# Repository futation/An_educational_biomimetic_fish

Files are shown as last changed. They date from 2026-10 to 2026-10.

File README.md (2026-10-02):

# 一种教育型仿生鱼

一种教育型仿生鱼，用于学生或者极客上手体验。

基于 Arduino Nano 的蓝牙遥控仿生机器鱼：3D 打印外壳 + 自焊 PCB + 防水舵机鱼尾，全套设计开源，适合作为中小学生与电子 DIY 爱好者的手工/电子入门项目。

English documentation: see [`使用说明（英文版）/`](使用说明（英文版）/Getting%20Started.md)

## 功能特点

- 蓝牙遥控：BLE / SPP 双模串口透传，手机发指令即可控制
- 多档摆动控制：±15° / ±30° / ±45° 摆幅，低速 / 高速两档，支持鱼尾回中与持续左右摆动
- 中位角度可通过指令调节，掉电保存于 EEPROM
- 全套开源：源码、PCB 工程、3D 打印外壳、组装与使用教程

## 仓库结构

| 目录 | 内容 |
| --- | --- |
| `Code/` | Arduino Nano 源码（`fish.ino` 与舵机/模式/EEPROM 模块） |
| `PCB/` | 立创EDA专业版 PCB 工程（`PCB.epro2`） |
| `外壳文件/` | 3D 打印外壳 STEP 文件（对接版本 / 旋钮版本两种方案） |
| `使用说明/` | 上手教程与控制指令说明（中文，md + pdf） |
| `使用说明（英文版）/` | English documentation (md + pdf) |
| `组装说明/` | 从 0 到 1 组装教程：备料、焊接、烧录、下水防水 |
| `软件/` | 配套手机端蓝牙调试软件（第三方转载，见其 README） |
| `image/` | 各说明文档所引用的图片与演示视频 |

## 快速上手

1. **组装**：3D 打印外壳，按 [组装说明](组装说明/仿生鱼V1.md) 完成备料、PCB 焊接、舵机安装与配重
2. **烧录**：安装 Arduino IDE，打开 `Code/fish/fish.ino`，开发板选 Arduino Nano，按文档处理烧录时的蓝牙占用问题
3. **连接**：手机安装 [`软件/蓝牙调试器_v1.95.apk`](软件/蓝牙调试器_v1.95.apk)（第三方软件，版权归原作者所有），磁铁开启小鱼电源后蓝牙连接
4. **控制**：发送 `CMD_a` / `CMD_A` 等指令让鱼游起来，详见 [使用说明](使用说明/鱼上手说明.md) 与 [控制命令说明](使用说明/鱼控制命令说明.md)

## 开发环境

- 主控：Arduino Nano（ATmega328P），Arduino IDE + Servo 库
- 蓝牙：DX-BT04 双模透传模块（建议选带 BLE 协议的型号）
- EDA：立创EDA专业版（直接打开 `PCB/PCB.epro2`）
- 外壳：通用 FDM 3D 打印机，STEP 格式可直接导入切片/建模软件

## 许可证

本项目以 [MIT](LICENSE) 协议开源。

其中 `软件/蓝牙调试器_v1.95.apk` 为第三方软件的转载，仅供下载便利，版权归其原作者所有；也可以改用任意其他 BLE 调试工具。

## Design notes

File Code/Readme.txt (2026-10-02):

For simplicity, 
SmartFish developed using Arduino IDE and Arduino Nano as the main controller. 
The source code is provided in this folder for learning purposes

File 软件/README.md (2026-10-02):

# 软件

本目录存放仿生鱼的配套手机端控制软件安装包。

| 文件 | 说明 |
| --- | --- |
| `蓝牙调试器_v1.95.apk` | Android 蓝牙调试软件，用于给小鱼发送控制指令（安装包原名 `lanyatiaoshiqi_v1.95_3673.com.apk`） |

## 来源说明

**该软件来自第三方网络，本项目仅转载安装包以便读者下载使用，软件版权归原开发者所有。**

- 软件名称：蓝牙调试器（BT Controller）
- 版本：v1.95
- 开发者：XieLazyDog（Xie Rongji）
- 开发者主页：<https://github.com/xielazydog>
- 应用仓库：<https://github.com/xielazydog/BTController>

如开发者不希望该软件被转载，请联系删除。你也可以在应用商店自行搜索"蓝牙调试器"获取最新版本。

> 其他任意支持 BLE 的蓝牙调试软件（如 BLE 调试助手）同样可用于控制小鱼。

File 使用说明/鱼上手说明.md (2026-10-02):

本项目小鱼是一款 兴趣教学 类 产品 ，为中小学生 ，电子 DIY 爱好者 提供 愉快的 手工项目体验。

以下为小鱼的直接上手体验教程：

***

### 安装控制软件

第一步，我们需要准备好 小鱼的控制软件。

小鱼 基于蓝牙协议进行控制，因此，您需要在电脑上或者手机 安装好 蓝牙指令软件 ：例如 BLE调试助手/蓝牙调试器等软件

我们先以 手机 的 蓝牙调试器 为例（安装包已随仓库提供：[软件/蓝牙调试器_v1.95.apk](../软件/蓝牙调试器_v1.95.apk)，该软件来自第三方网络，版权归原作者所有）

安装完成后，您的手机会显示该图标

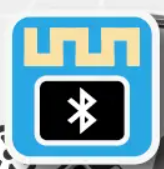
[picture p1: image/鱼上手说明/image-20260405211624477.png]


当然，其他任何的 蓝牙调试软件都是被允许使用的。

***

### 打开开关

由于小鱼采用磁控开关，首先，我们需要准备 胶布和磁铁，并把磁铁粘贴在胶布上

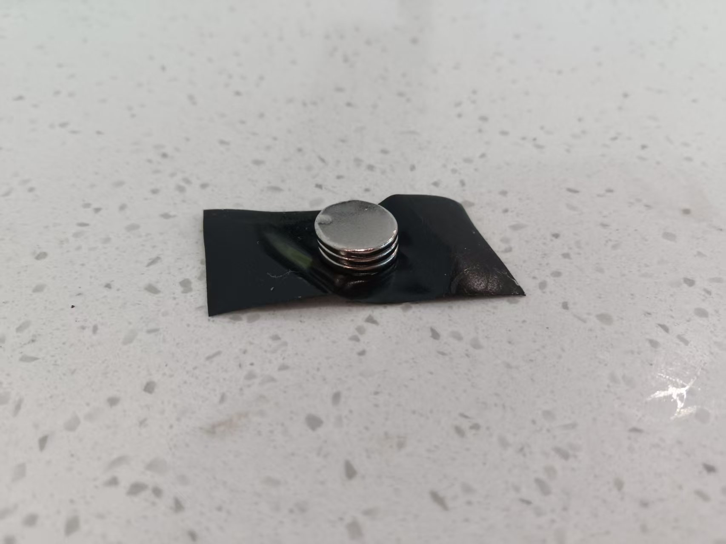
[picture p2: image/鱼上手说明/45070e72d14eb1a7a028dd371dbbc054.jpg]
45070e72d14eb1a7a028dd371dbbc054


再把胶布粘在小鱼顶部的位置，如下图

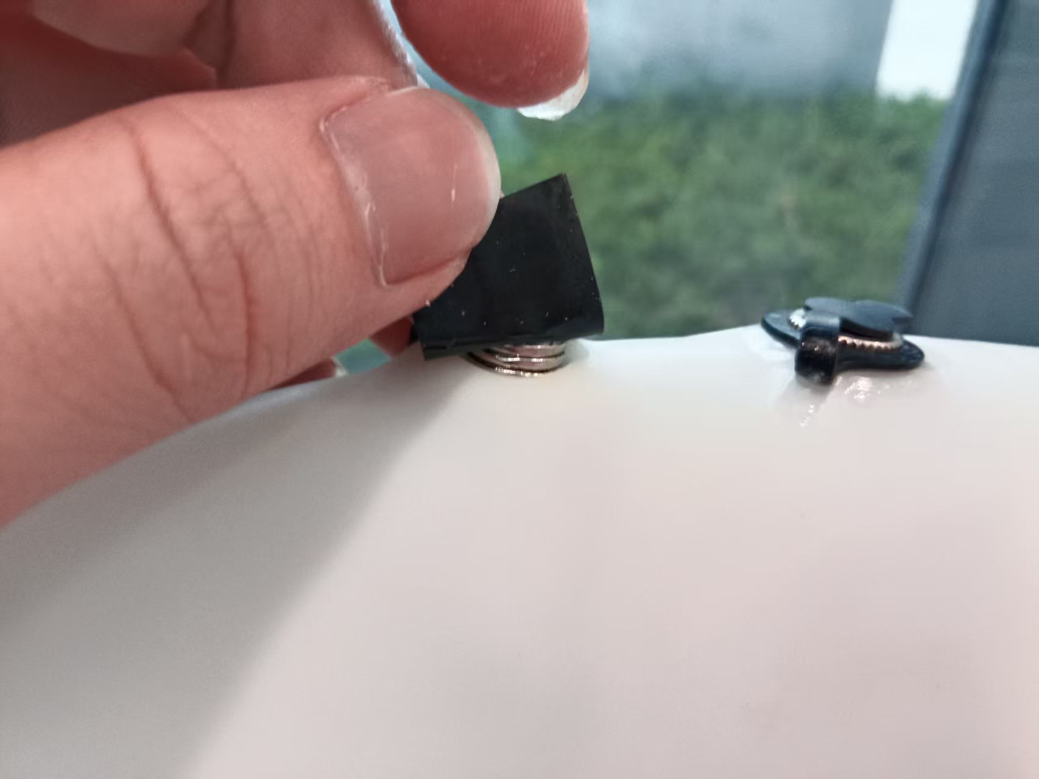
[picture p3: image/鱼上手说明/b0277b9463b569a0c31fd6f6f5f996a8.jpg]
b0277b9463b569a0c31fd6f6f5f996a8


如果能听到“咔哒”一声（继电器打开的声音），说明小鱼已正常打开。

***

### 连接小鱼

点击并打开 安装好的 蓝牙软件，扫描蓝牙 并连接上 小鱼的 蓝牙

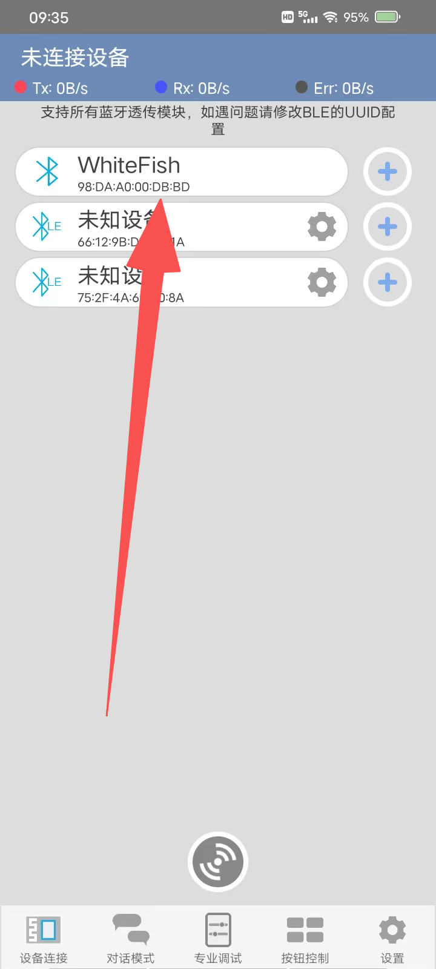
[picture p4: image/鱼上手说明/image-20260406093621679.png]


> 如果蓝牙调试器没有扫描到任何设备，请检查 手机的 定位/蓝牙服务 是否正常开启

连接完成后，软件显示的界面如下图：

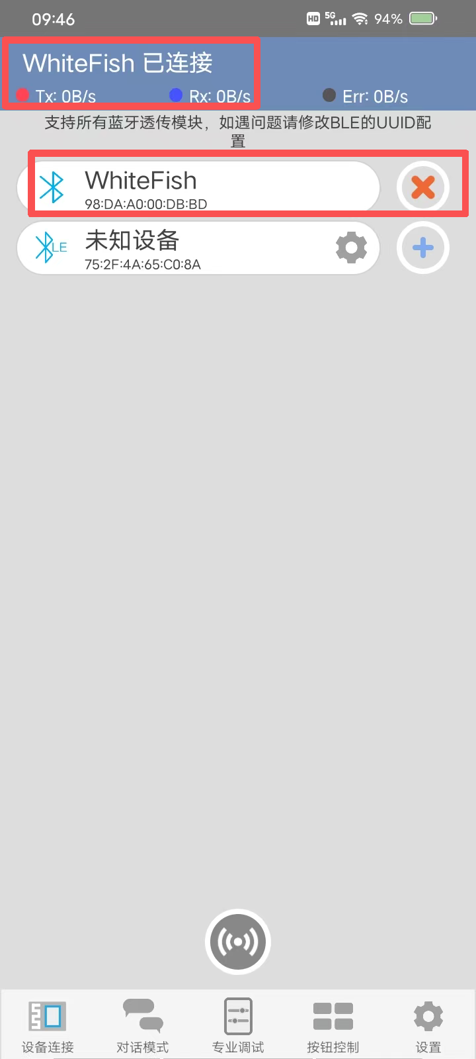
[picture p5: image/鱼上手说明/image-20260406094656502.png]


> 首次连接 可能需要 输入 PIN ，此时输入 0000 或者 1234 即可

连接上小鱼，之后 打开对话模式，发送指令 `CMD_a` 

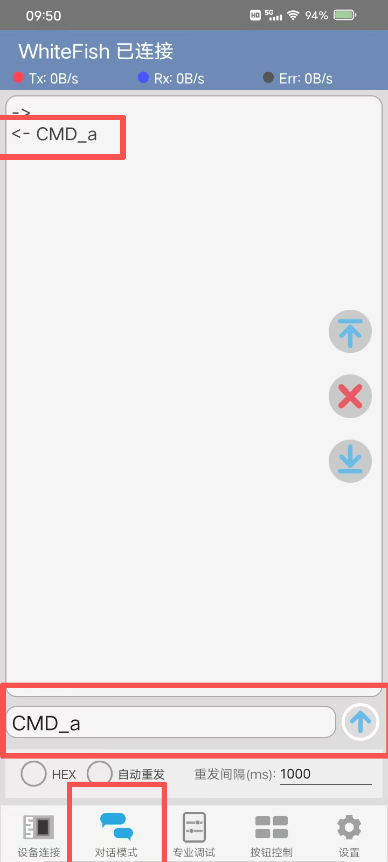
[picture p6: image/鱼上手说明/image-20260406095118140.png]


如果小鱼 此时鱼尾开始 轻微摆动 ，说明 小鱼系统正常工作。

***

对于一些其他专业的蓝牙调试软件，连接完成之后，显示界面可能如下：

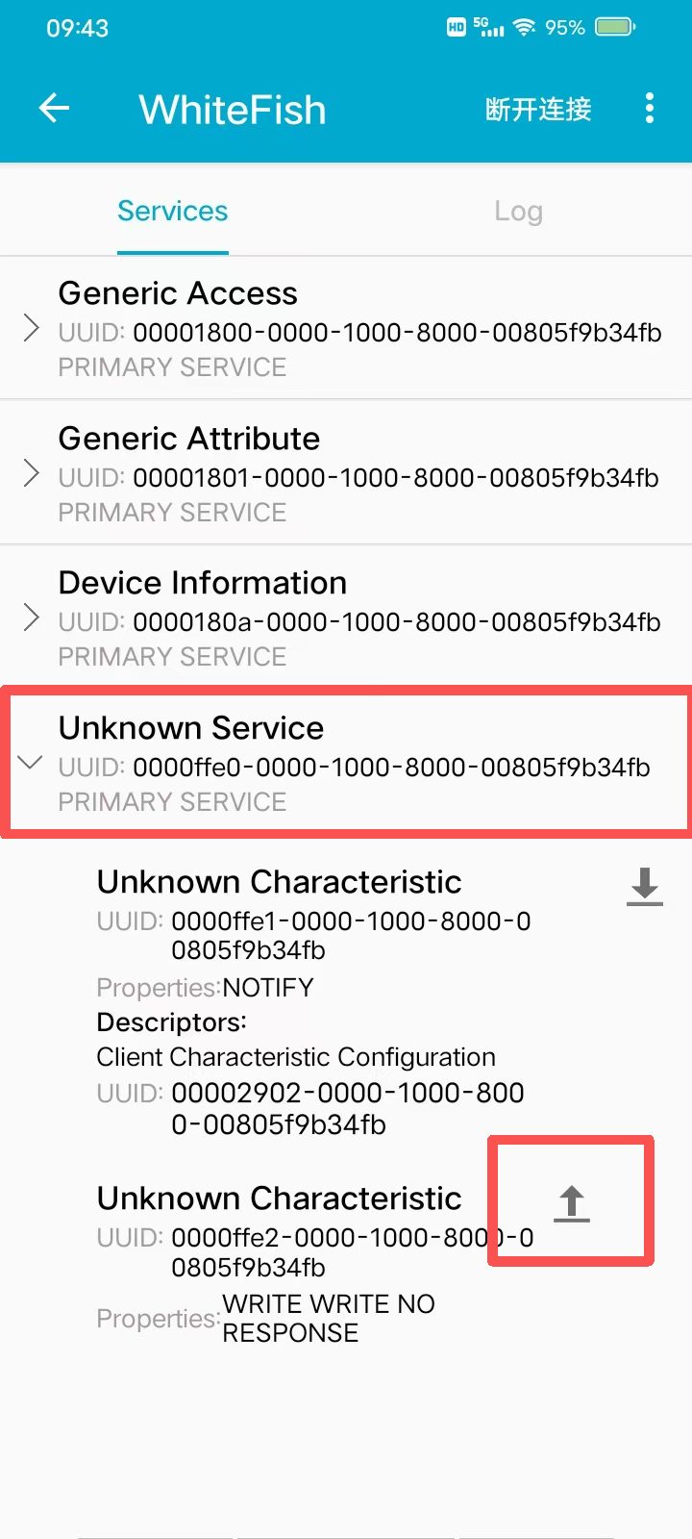
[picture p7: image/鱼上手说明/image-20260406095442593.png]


此时，我们选择 `Unknown Service`，选择 上传服务

在此发送 对应的命令即可

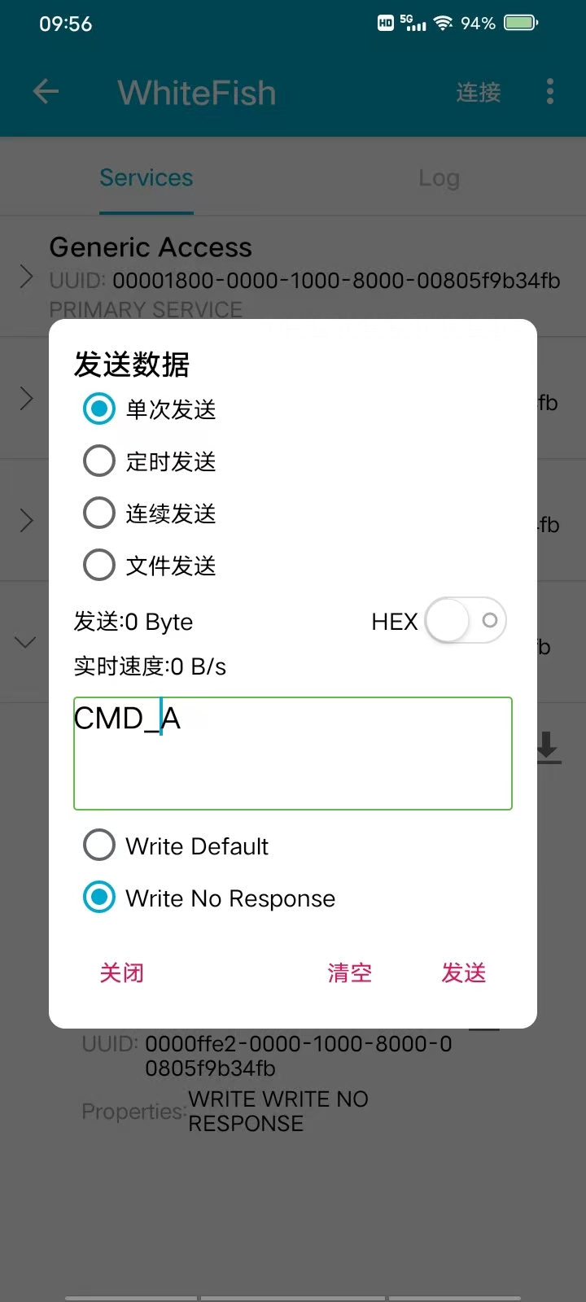
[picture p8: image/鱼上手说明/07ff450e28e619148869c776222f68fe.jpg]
07ff450e28e619148869c776222f68fe


### 更多指令

小鱼系统正常工作后，您现在可以尝试发送更多的指令，一些基础的指令如下：

| 命令 | 功能描述 |
| --- | --- |
| `CMD_S` | 鱼尾回归中心位置 |
| `CMD_R` | 鱼尾持续右方摆动 |
| `CMD_L` | 鱼尾持续左方摆动 |
| `CMD_a` | ±15°摆动（低速） |
| `CMD_A` | ±15°摆动（高速） |
| `CMD_b` | ±30°摆动（低速） |
| `CMD_B` | ±30°摆动（高速） |
| `CMD_c` | ±45°摆动（低速） |
| `CMD_C` | ±45°摆动（高速） |

更多 自定义的高级指令，请阅读文件夹目录下文档：[鱼控制命令说明](鱼控制命令说明.pdf)

***

### 自定义控制按键

频繁的编辑指令文本 对操作可能比较繁琐

对此，您可以打开蓝牙调试的这个界面

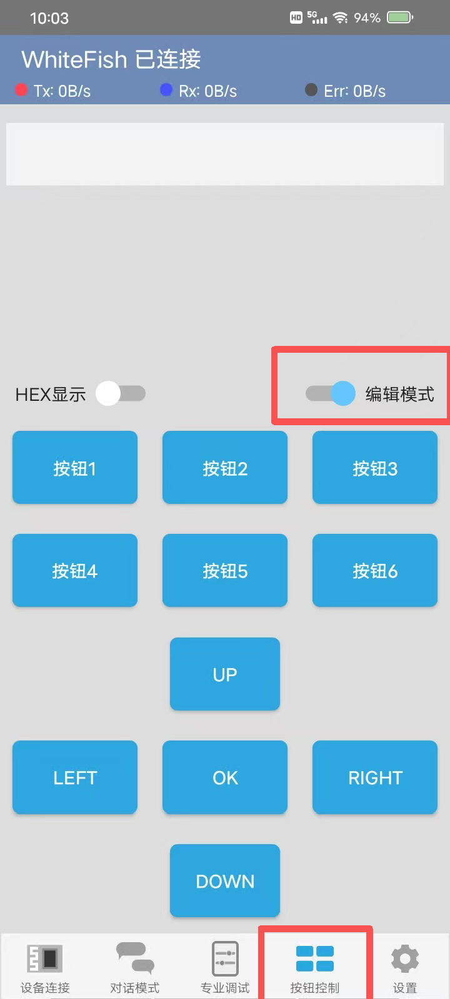
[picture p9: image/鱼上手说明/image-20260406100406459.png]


首先，我们需要 打开 编辑模式

此时，选中某个按钮，我们可以自定义编辑要发送的指令

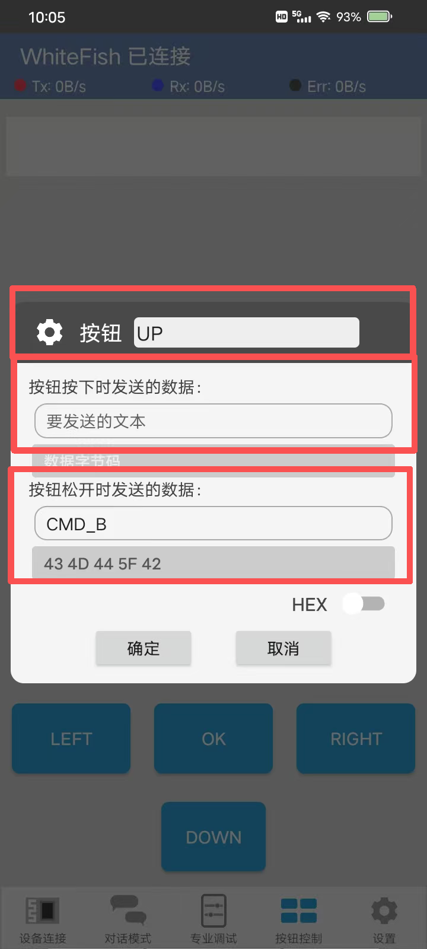
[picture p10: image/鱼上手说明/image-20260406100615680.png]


此时，我们可以 编辑 按钮的名称 和 按键按下 和 按键松开时 发送的数据 （这里，我们只需要 编辑 按下事件或者松开 事件 其中任意一个 数据文本即可）

注意，请不要打开 `HEX` 发送 ！！！

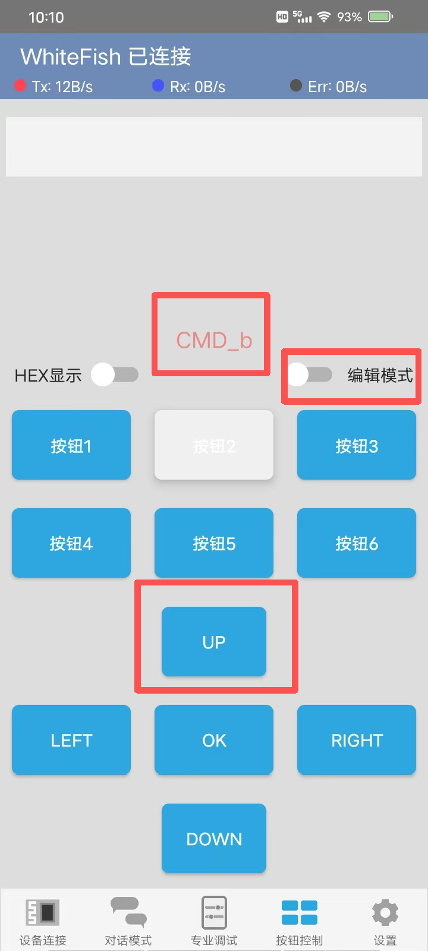
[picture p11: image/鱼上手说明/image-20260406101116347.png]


***

### 关于下水

注意，如果小鱼准备下水，需要 添加额外的防水措施，包括但不限于：

* 添加并调整配重，保证小鱼半浮在水面上，并保持平衡
* 鱼内部的电子器件需要添加密封袋 做 防水保护
* 鱼对接内部旋钮部分建议缠上生料带以添加防水性
* 鱼 外层对接处需要 防水胶布 以确保 系统性防水。

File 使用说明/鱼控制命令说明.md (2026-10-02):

小鱼一共有三种操作模式：基础模式，中心校准模式，自定义模式

小鱼上电打开后 自动 进入基础模式

***

### 1. 基础模式（默认模式）

> 基础模式为默认游动模式，用于直接控制鱼的运动
>
> 向鱼发送CMD_D’，‘CMD_E’可进入其他两个调试模式

- **功能**：执行预设动作（回中、左右转、固定幅度摆动）；
- **进入方式**：系统上电默认进入，或在其他模式下发送`X`返回。

| 命令 | 功能描述 |
| --- | --- |
| `CMD_S` | 舵机回归中心位置 |
| `CMD_R` | 舵机持续右方摆动 |
| `CMD_L` | 舵机持续左方摆动 |
| `CMD_a` | ±15°摆动（低速） |
| `CMD_A` | ±15°摆动（高速） |
| `CMD_b` | ±30°摆动（低速） |
| `CMD_B` | ±30°摆动（高速） |
| `CMD_c` | ±45°摆动（低速） |
| `CMD_C` | ±45°摆动（高速） |

***

> 这个模式用于校准舵机中心位置
>
> 虽然已经调好舵机中心位置为90度
>
> 但是时间久了可能会有偏差，所以，利用这个模式来确定鱼尾在中心的时，舵机为多少度

### 2. 中心设置模式

- **功能**：自定义舵机的中心位置（默认中心可通过此模式校准）；
- **进入方式**：在基础模式下发送`CMD_D`。

| 操作 | 功能描述 | 限制条件 |
| --- | --- | --- |
| 输入数字（`CMD_0`-`CMD_180`） | 设置舵机当前角度为新中心 | 角度需在0-180度范围内，超出范围会提示错误 |
| 发送`CMD_X` | 返回基础模式 | 退出前会清空残留输入，避免干扰 |

**注意：**设置的角度将会被主控芯片闪存记忆，下次通电的时候，中心角度依旧是上次设置的值。

***

> 确定好鱼的中心是多少度的时候，我们就可以根据这个位置来控制摆动
>
> 这个模式我们可以选择舵机持续在两个指定的角度摆动
>
> 延时可以理解为，舵机每动一度，延时多少毫秒。这个值越大，鱼尾摆动速度越慢。

### 3. 自定义模式

- **功能**：自由设定舵机摆动的角度范围和每步延迟时间；
- **进入方式**：在基础模式下发送`CMD_E`。

#### 输入格式1

注意需发送逗号以分隔的三个参数：`CMD_角度1,角度2,延时ms`  
- **角度1/角度2**：舵机摆动的两个端点角度（如70和110，舵机会在70°与110°之间往返）；  
- **延时ms**：舵机从一个角度移动到另一个角度的每步间隔时间（影响摆动速度）。

#### 参数限制

- 角度：0-360度（超出范围会提示错误）；  
- 延时：1-1000ms（过小可能导致舵机卡顿，过大会降低响应速度）。

#### 操作命令
| 操作 | 功能描述 |
| --- | --- |
| 发送参数（如`70,110,20`） | 按设定角度和延时循环摆动，直到发送新命令 |
| 发送`X` | 返回基础模式，停止当前摆动 |

**示例**：  
发送`CMD_70,110,20` → 串口显示“✅ 自定义摆动: 70° ↔ 110°, 延时20ms”，舵机开始往返摆动；  
发送`CMD_0,180,500` → 舵机在0°到180°之间缓慢摆动，每步间隔500ms。

***

#### 输入格式2

> 对比真鱼：鱼的尾巴不是不间断，摆动几下，鱼就会停下来休息的
>
> 自定义模式下支持模仿鱼的停止时间

注意需发送以逗号分隔的五个参数：`CMD_角度1,角度2,延时ms,摆动周期,停止时间`  

- **角度1/角度2**：舵机摆动的两个端点角度（如70和110，舵机会在70°与110°之间往返）；  
- **延时ms**：舵机从一个角度移动到另一个角度的每步间隔时间（影响摆动速度）。
- **摆动周期**：舵机摆动的周期
- **停止时间**：完整N个周期（N是上一个参数）之后，停止的时间，单位是ms

#### 操作命令

| 操作 | 功能描述 |
| --- | --- |
| 发送参数（如`CMD_70,110,20,3,2000`） | 在70和110度之间摆动，步近延时15ms（控制速度），摆动3个周期后，会停止2秒，然后继续摆动3个周期... |
| 发送`CMD_X` | 返回基础模式，停止当前摆动 |

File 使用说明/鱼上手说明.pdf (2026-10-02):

本项目小鱼是一款 兴趣教学 类 产品 ，为中小学生 ，电子 DIY 爱好者 提供 愉快的 手工项目体验。

以下为小鱼的直接上手体验教程：

## 安装控制软件

第一步，我们需要准备好 小鱼的控制软件。

小鱼 基于蓝牙协议进行控制，因此，您需要在电脑上或者手机 安装好 蓝牙指令软件 ：例如 BLE调试助 手/蓝牙调试器等软件

我们先以 手机 的 蓝牙调试器 为例，（软件的安装包 路径在本文件夹目录下已 提供 如下：蓝牙调试器 ）

安装完成后，您的手机会显示该图标

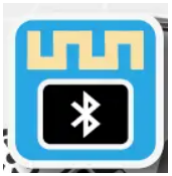
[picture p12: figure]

当然，其他任何的 蓝牙调试软件都是被允许使用的。

## 打开开关

由于小鱼采用磁控开关，首先，我们需要准备 胶布和磁铁，并把磁铁粘贴在胶布上


再把胶布粘在小鱼顶部的位置，如下图


如果能听到“咔哒”一声（继电器打开的声音），说明小鱼已正常打开。

## 连接小鱼

点击并打开 安装好的 蓝牙软件，扫描蓝牙 并连接上 小鱼的 蓝牙


如果蓝牙调试器没有扫描到任何设备，请检查 手机的 定位/蓝牙服务 是否正常开启

连接完成后，软件显示的界面如下图：

首次连接 可能需要 输入 PIN ，此时输入 0000 或者 1234 即可

连接上小鱼，之后 打开对话模式，发送指令 CMD_a


如果小鱼 此时鱼尾开始 轻微摆动 ，说明 小鱼系统正常工作。

对于一些其他专业的蓝牙调试软件，连接完成之后，显示界面可能如下：


此时，我们选择 Unknown Service ，选择 上传服务

在此发送 对应的命令即可

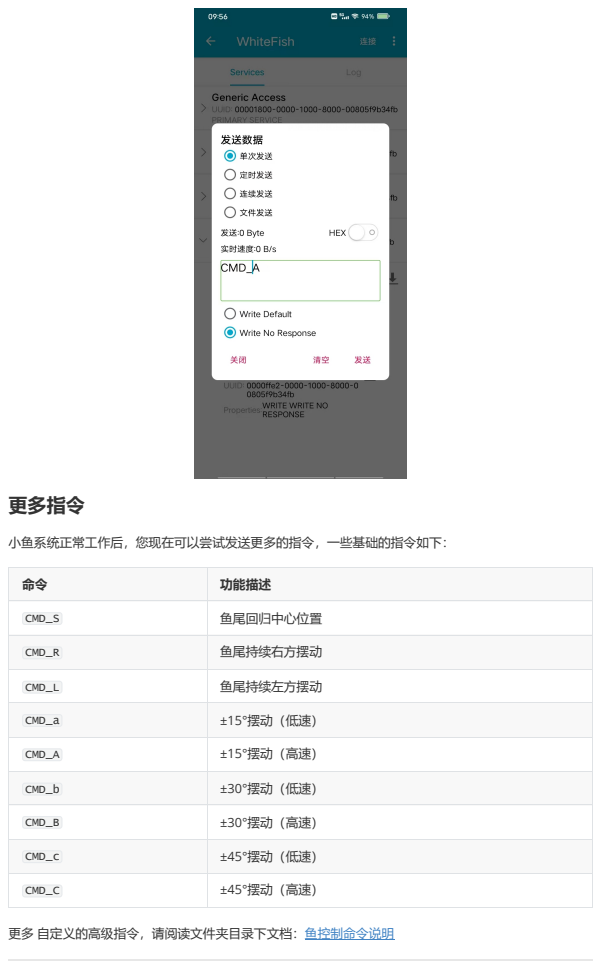
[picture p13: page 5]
更多指令

小鱼系统正常工作后，您现在可以尝试发送更多的指令，一些基础的指令如下：

命令 | 功能描述

CMD_S | 鱼尾回归中心位置

CMD_R | 鱼尾持续右方摆动

CMD_L | 鱼尾持续左方摆动

CMD_a | ±15°摆动（低速）

CMD_A | ±15°摆动（高速）

CMD_b | ±30°摆动（低速）

CMD_B | ±30°摆动（高速）

CMD_c | ±45°摆动（低速）

CMD_C | ±45°摆动（高速）

更多 自定义的高级指令，请阅读文件夹目录下文档：鱼控制命令说明

## 自定义控制按键

频繁的编辑指令文本 对操作可能比较繁琐

对此，您可以打开蓝牙调试的这个界面

首先，我们需要 打开 编辑模式

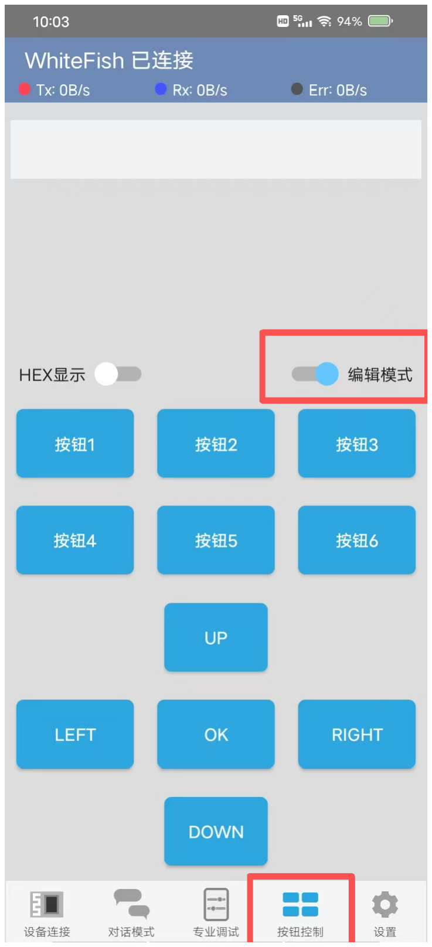
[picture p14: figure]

此时，选中某个按钮，我们可以自定义编辑要发送的指令

此时，我们可以 编辑 按钮的名称 和 按键按下 和 按键松开时 发送的数据 （这里，我们只需要 编辑 按下 事件或者松开 事件 其中任意一个 数据文本即可）

注意，请不要打开 HEX 发送 ！！！

## 关于下水

注意，如果小鱼准备下水，需要 添加额外的防水措施，包括但不限于：

添加并调整配重，保证小鱼半浮在水面上，并保持平衡
鱼内部的电子期间需要添加密封袋 做 防水保护
鱼对接内部旋钮部分建议缠上生料带以添加防水性
鱼 外层对接处需要 防水胶布 以确保 系统性防水。

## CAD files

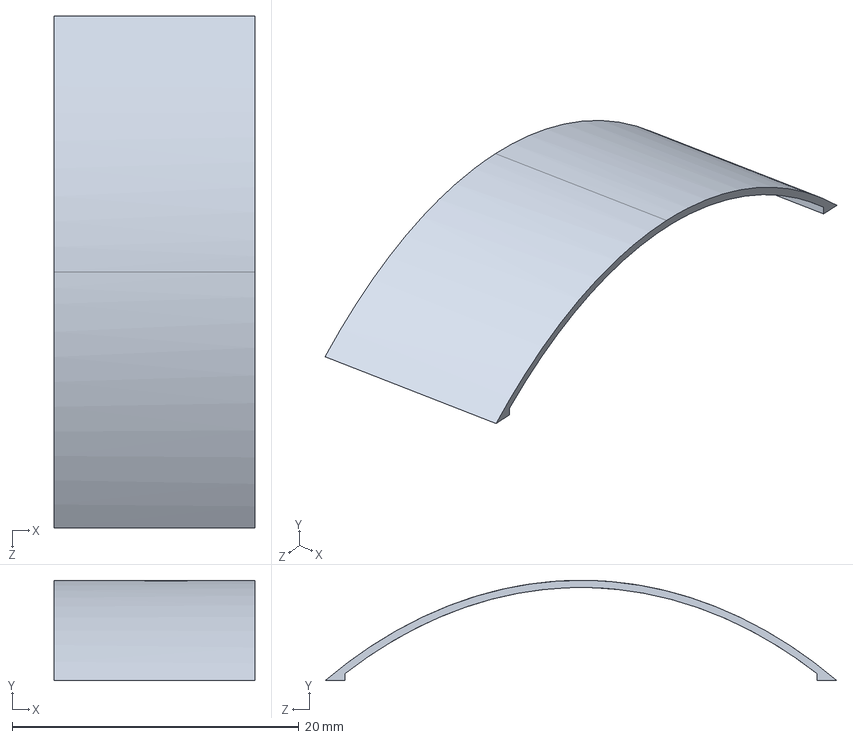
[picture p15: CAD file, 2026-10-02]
外壳文件/1.对接版本/端盖1.STEP
14.0 x 7.00 x 35.7 mm

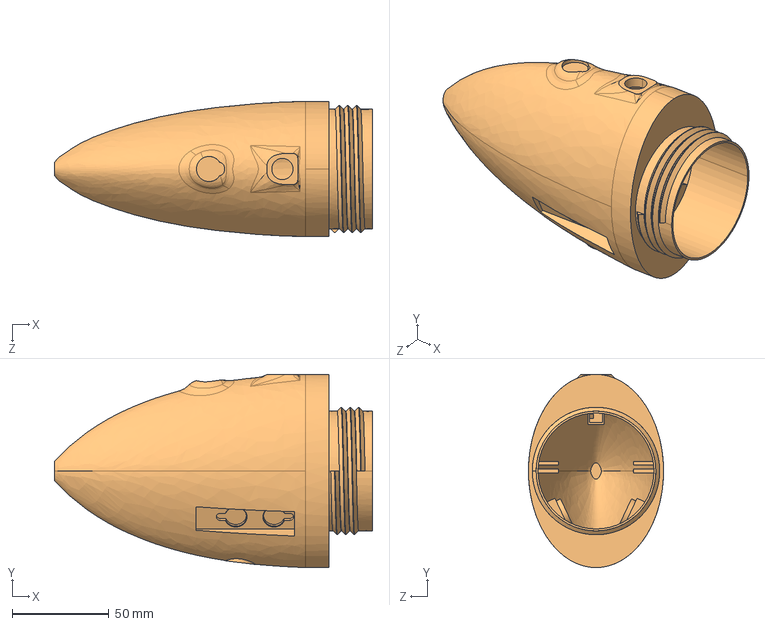
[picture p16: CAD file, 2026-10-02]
外壳文件/2.旋钮版本/鱼前身.STEP
164.6 x 100.0 x 70.0 mm

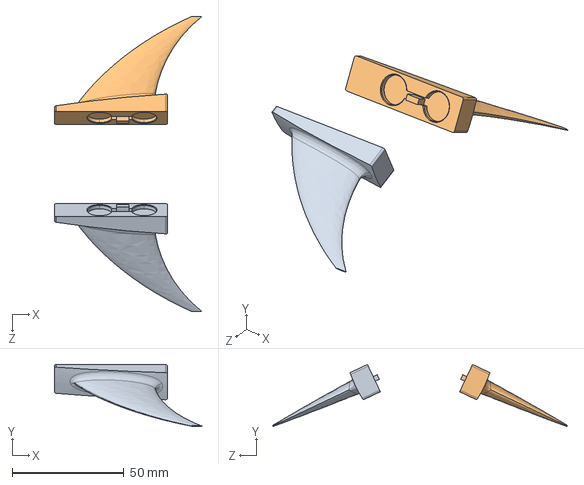
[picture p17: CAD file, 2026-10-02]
外壳文件/1.对接版本/胸鳍右.STEP
65.8 x 27.7 x 131.8 mm

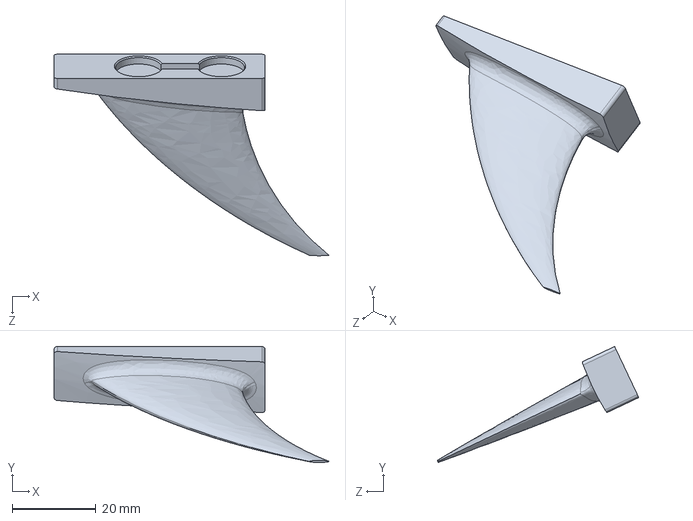
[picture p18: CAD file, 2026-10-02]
外壳文件/2.旋钮版本/左胸鳍.STEP
65.8 x 27.7 x 48.2 mm

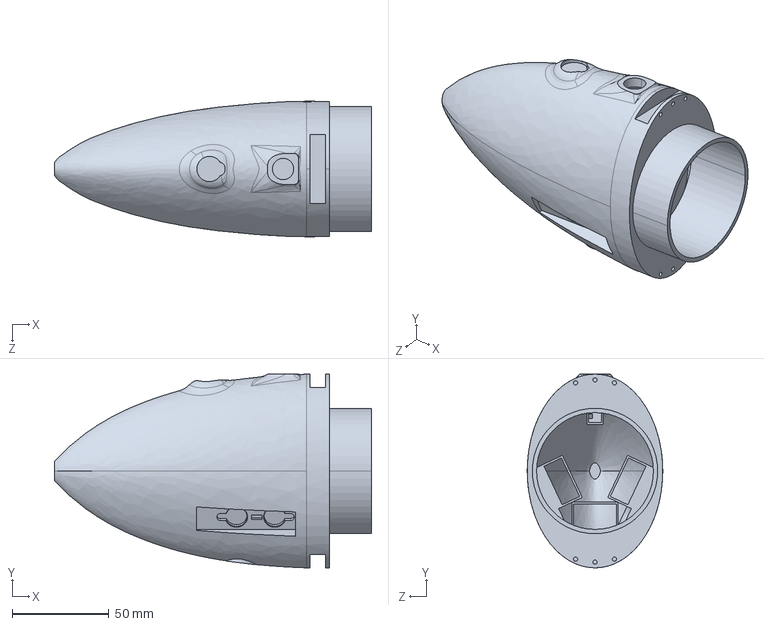
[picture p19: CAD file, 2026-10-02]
外壳文件/1.对接版本/前盖.STEP
163.6 x 100.0 x 70.0 mm

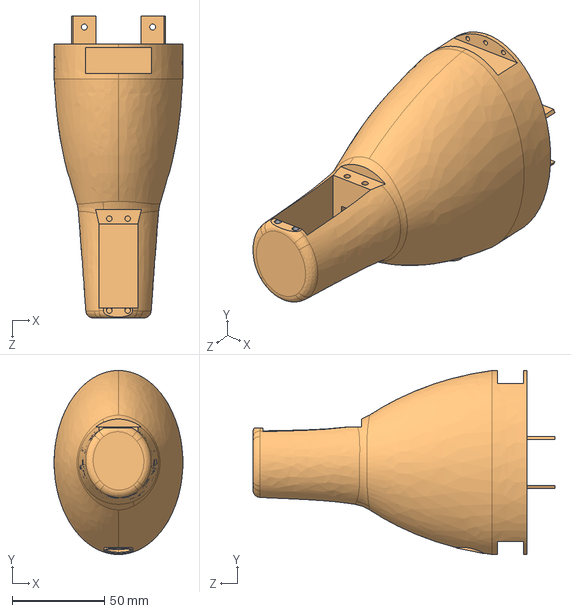
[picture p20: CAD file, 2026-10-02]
外壳文件/1.对接版本/后壳单轴舵机.STEP
70.0 x 100.0 x 164.1 mm

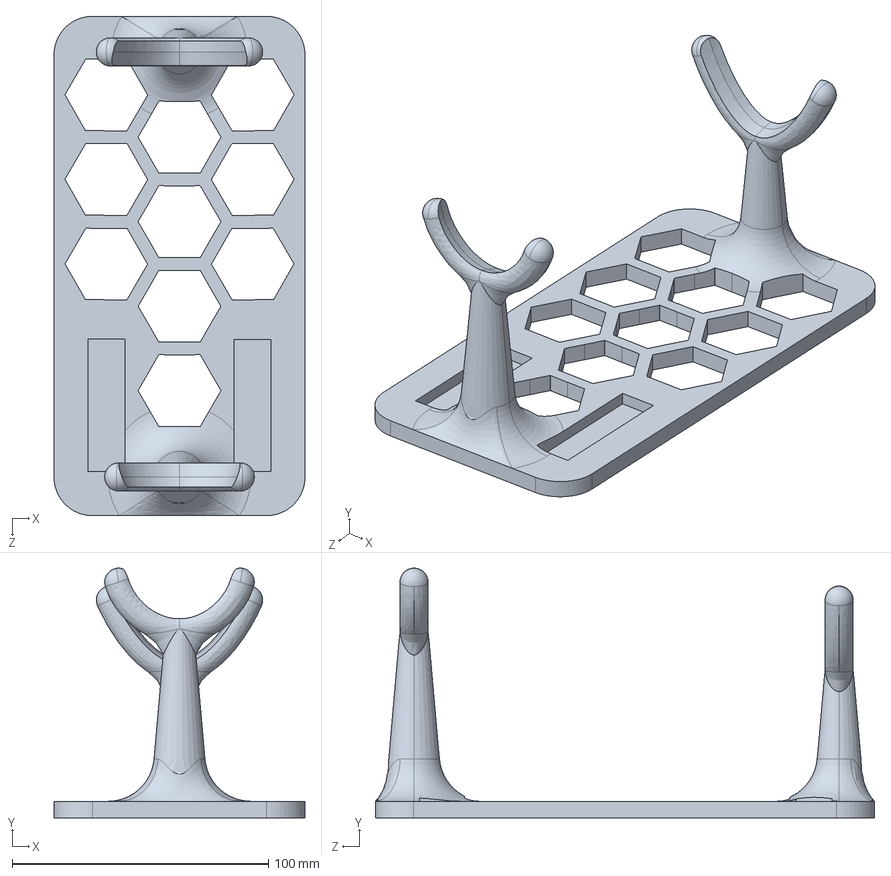
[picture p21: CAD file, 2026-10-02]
外壳文件/2.旋钮版本/底座.STEP
98.0 x 97.6 x 195.0 mm

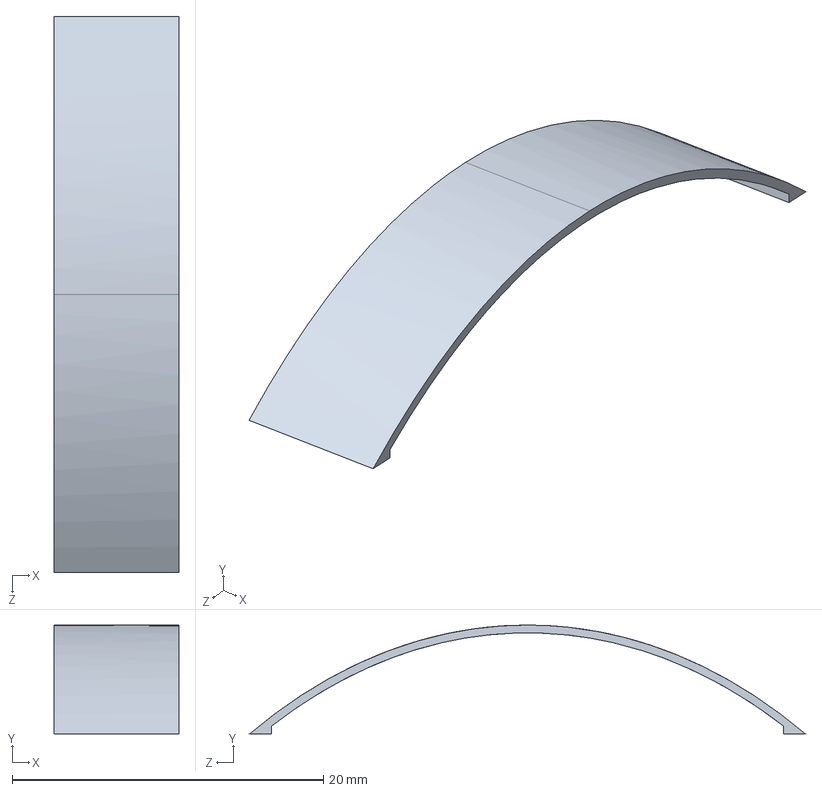
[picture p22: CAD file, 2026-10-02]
外壳文件/1.对接版本/端盖.STEP
8.00 x 7.00 x 35.7 mm

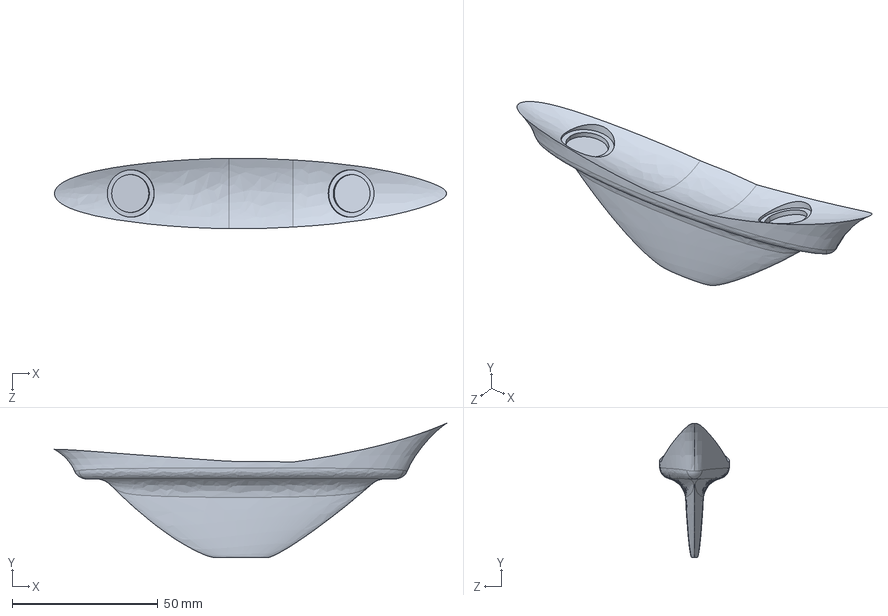
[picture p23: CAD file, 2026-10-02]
外壳文件/2.旋钮版本/腹鳍.STEP
134.3 x 46.1 x 24.1 mm

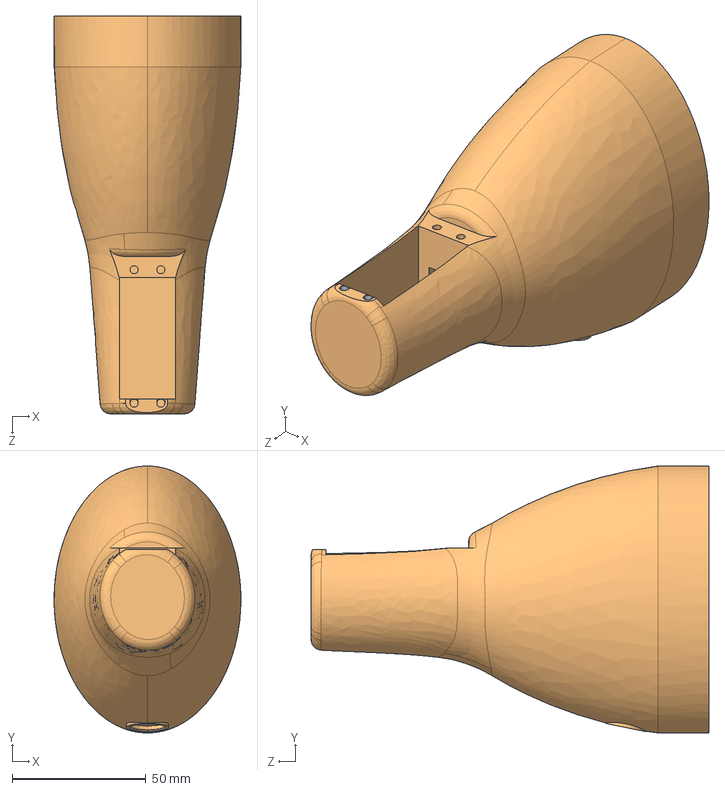
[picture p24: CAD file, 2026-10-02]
外壳文件/2.旋钮版本/鱼后壳.STEP
69.9 x 100.0 x 149.0 mm

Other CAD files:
外壳文件/2.旋钮版本/右胸鳍.STEP

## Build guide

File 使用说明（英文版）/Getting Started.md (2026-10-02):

# Getting Started with the Smart Fish

The Smart Fish Kit is an educational product tailored for primary and secondary school students, as well as electronic DIY enthusiasts, to deliver an engaging hands-on project experience.

Below is a step-by-step guide to getting started with the Smart Fish :

***

### Installing the Control Software

First, we need to set up the control software for the Smart Fish Kit.

The Smart Fish Kit is controlled via Bluetooth protocol, so you will need to install a Bluetooth command utility (e.g., BLE Debug Assistant/Bluetooth Debugger) on your computer or mobile phone.

Let’s take the mobile version of Bluetooth Debugger as an example. (The installation package is provided in the repository at [软件/蓝牙调试器_v1.95.apk](../软件/蓝牙调试器_v1.95.apk). Note that this software is a third-party app, and all copyrights belong to its original author.)

Once installed, the app icon will appear on your mobile phone screen.



Of course, any other Bluetooth debugging software is also compatible.

***

### Powering On the Device
The Smart Fish Kit uses a magnetic control switch. To power it on:
1. Prepare a piece of adhesive tape and a magnet.
2. Attach the magnet to the adhesive tape.

45070e72d14eb1a7a028dd371dbbc054

3. Stick the tape (with the magnet) to the top of the Smart Fish Kit, as shown below.

b0277b9463b569a0c31fd6f6f5f996a8

A "click" sound (from the relay activation) confirms that the Smart Fish has been powered on successfully.

***

### Connecting to the Smart Fish Kit
1. Launch the installed Bluetooth software.
2. Scan for Bluetooth devices and connect to the Smart Fish Kit’s Bluetooth signal.



> If no devices are detected by the Bluetooth Debugger, check that your phone’s location and Bluetooth services are enabled.

After a successful connection, the software interface will look like this:



> A PIN code may be required for the first connection. Enter `0000` or `1234` if prompted.

3. Once connected, enable chat mode and send the command `CMD_a`.



A slight wag of the fish’s tail confirms that the Smart Fish Kit is functioning properly.

***

For other professional Bluetooth debugging software, the post-connection interface may look like this:



In this case:
1. Select `Unknown Service`.
2. Choose the "Upload Service" option.
3. Send the corresponding commands here.

07ff450e28e619148869c776222f68fe

### Additional Commands
Once the Smart Fish Kit is operational, you can try sending additional commands. Basic commands are listed below:

| Command | Function Description |
| --- | --- |
| `CMD_S` | Return tail to center position |
| `CMD_R` | Continuous tail wag to the right |
| `CMD_L` | Continuous tail wag to the left  |
| `CMD_a` | ±15° wag (low speed) |
| `CMD_A` | ±15° wag (high speed) |
| `CMD_b` | ±30° wag (low speed) |
| `CMD_B` | ±30° wag (high speed) |
| `CMD_c` | ±45° wag (low speed) |
| `CMD_C` | ±45° wag (high speed) |

For more custom advanced commands, refer to the document in the folder: [Smart Fish Control Command Guide](Smart Fish Control Command Guide.PDF)

***

### Customizing Control Buttons
Repeatedly editing command text can be cumbersome during operation. To simplify this:

1. Open the following interface in the Bluetooth Debugger:



2. Enable edit mode.
3. Select a button to customize the command it sends.



4. Edit the button name and the data sent when the button is pressed or released (only one of the "press" or "release" event data fields needs to be configured).

> IMPORTANT: Do NOT enable HEX transmission!!!



***

### Notes for Underwater Use
If the Smart Fish Kit is to be used underwater, additional waterproofing measures are mandatory, including but not limited to:
- Add and adjust counterweights to ensure the kit floats semi-submerged and balanced on the water surface.
- Encase internal electronic components in a waterproof sealable bag for protection.
- Wrap Teflon tape around internal knob connections to enhance water resistance.
- Apply waterproof tape to external joints of the kit to ensure full system waterproofing.

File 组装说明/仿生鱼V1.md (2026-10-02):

本篇旨在 带新手 从0到1组装 出一条仿生鱼

所有步骤经过 大量的摸索与试错

当然，没有标准答案，如果有更优雅的组装方法 / 方案 欢迎指正提出

注意：下文给出的均为**淘宝搜索关键词**而非固定店铺链接，按关键词搜到同类商品即可，不必拘泥于示例店铺

***

# 配件准备

打印完鱼后，先准备一下基本部件：

### 1.电池充电口

这个需要注意方向外壳 （外边长条是 GND ，内条是 7.4V）

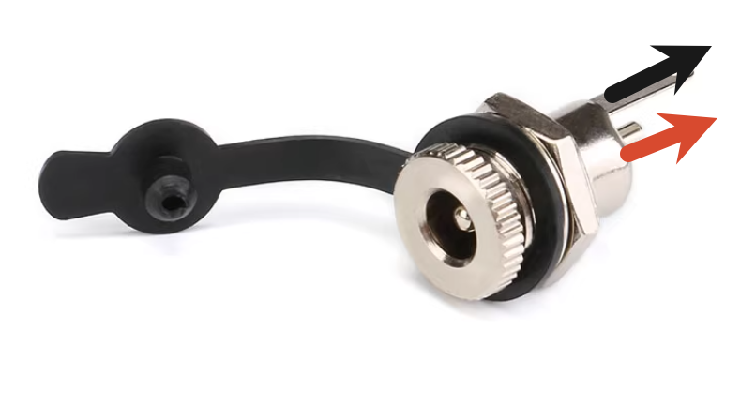
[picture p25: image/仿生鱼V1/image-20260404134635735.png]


如图所示，外壳长条需要接黑线（GND），內部短条 接 红线 （VCC）

该接口淘宝搜索关键词（与防水帽一并购买）：

**DC电源插座 DC-099 5.5*2.1 充电插座 母座 带防水帽**

线的另一端需要接 接线端子  

接线端子的 方向如下（插入 左边正 ，右边负）

特别注意，端子是有方向的

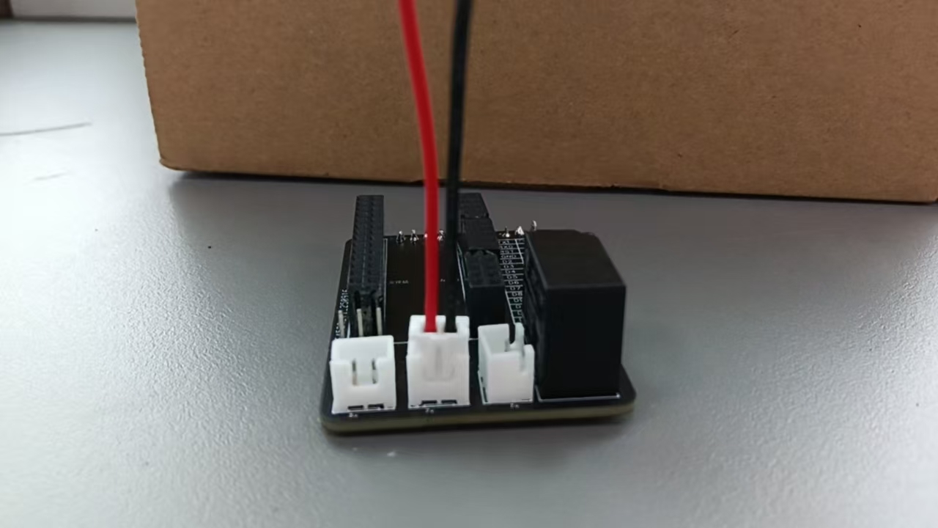
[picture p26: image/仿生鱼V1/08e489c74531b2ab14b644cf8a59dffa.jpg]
08e489c74531b2ab14b644cf8a59dffa


端子线淘宝搜索关键词：**XH2.54 2P 单头连接端子线 22AWG 红黑电源线**

这里需要注意 **左红右黑**、**22AWG**（线径）、**200mm**（长度）

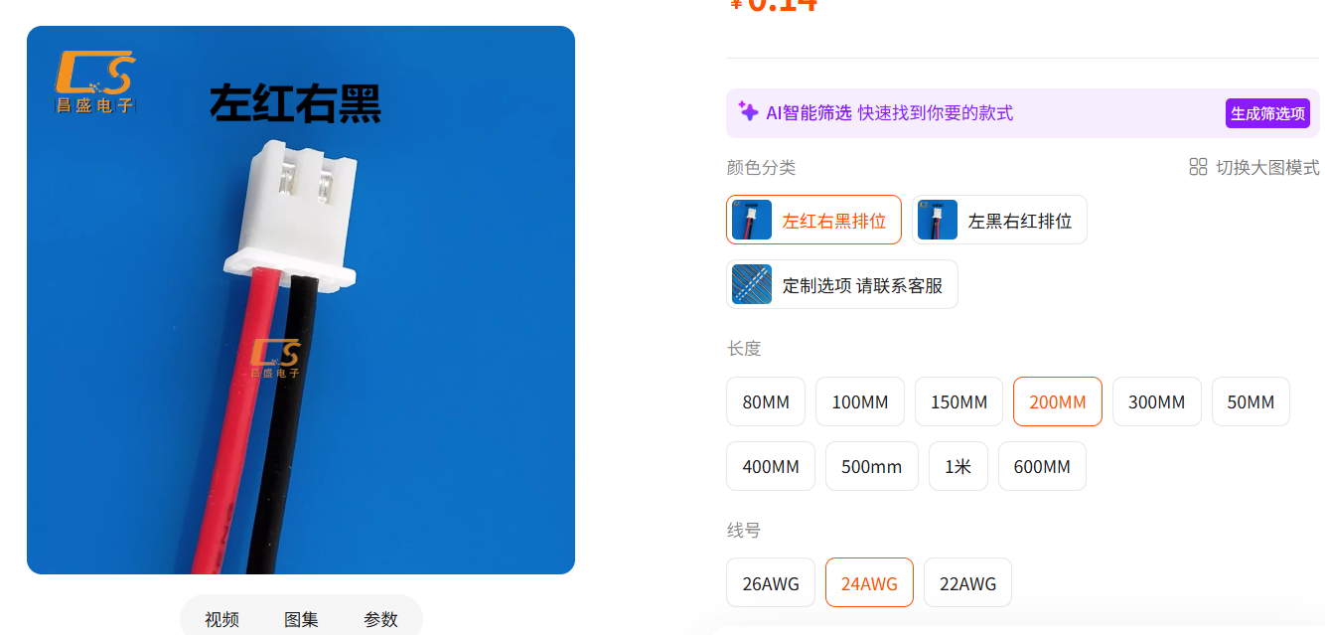
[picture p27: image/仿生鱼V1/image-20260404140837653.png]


最终预期效果

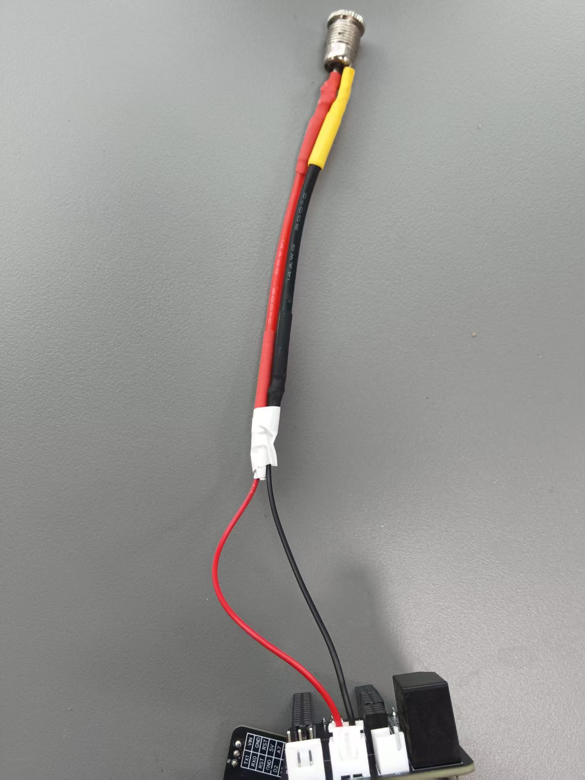
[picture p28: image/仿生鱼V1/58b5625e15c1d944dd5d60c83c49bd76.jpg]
58b5625e15c1d944dd5d60c83c49bd76


图为拼装线，故略微有瑕疵（此即为线材买错的下场）

**一定一定注意方向，千万千万不要接反**

这里再顺便提一下 PCB上的 胶壳接口

胶壳母座接口（焊在PCB上的）淘宝搜索关键词：

**XH2.54 直针 插头插座 接线端子**

注意是 2P（两根线） ，间距 2.54mm 直针的 ！！！

***

### 2.磁控开关

淘宝搜索关键词：

**GPS-23 磁控开关 常开常闭 干簧管 门磁开关**

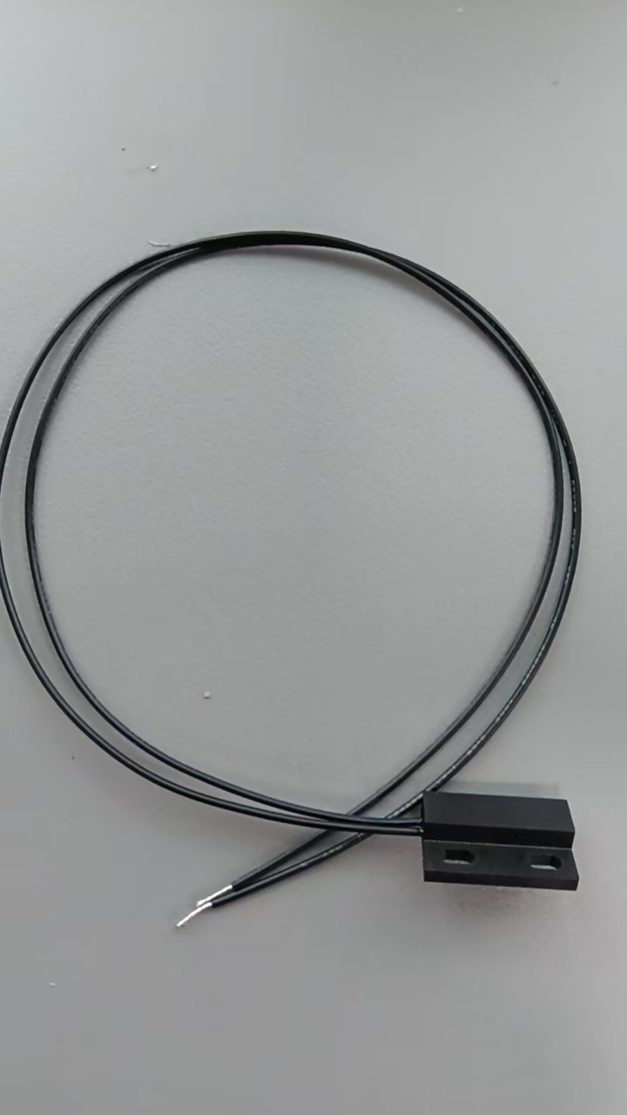
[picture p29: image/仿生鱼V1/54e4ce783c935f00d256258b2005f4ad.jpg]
54e4ce783c935f00d256258b2005f4ad


由于这个末端 为铜丝线 

为了 可拆卸方便 这个需要我们自己装上 接线端子 （强烈不建议直接焊接在PCB上）

（如果能找到支持 定做 接线端子的 商家 是最好的 ） 

装上接线端子 有两种方法：

1.**机械做法：**买端子壳 + PH2.54端子针 

需要用到的工具 ： 压线钳

**XH2.54 接插件连接器 端子插头 直针/弯针 2P/3P/4P**

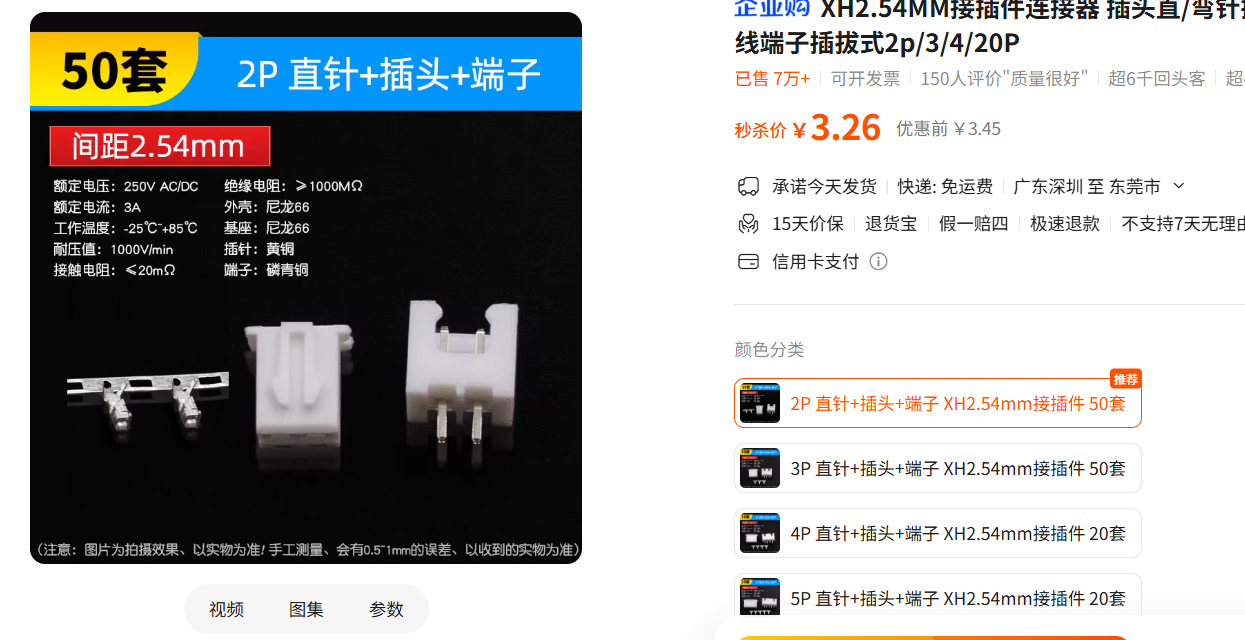
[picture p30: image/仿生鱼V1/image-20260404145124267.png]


具体操作教程示例视频：[【教程】XH2.54端子压线，三种方法教你入门_哔哩哔哩_bilibili](https://www.bilibili.com/video/BV1fGRmYrEZJ/)

2.**电工做法：**把线剪短一些 + 焊接之前买的 端子线

需要用到的工具：焊笔+热风枪

（本质上就是把两根线焊接在一起）

这里采用第二种方法，最终效果如图：

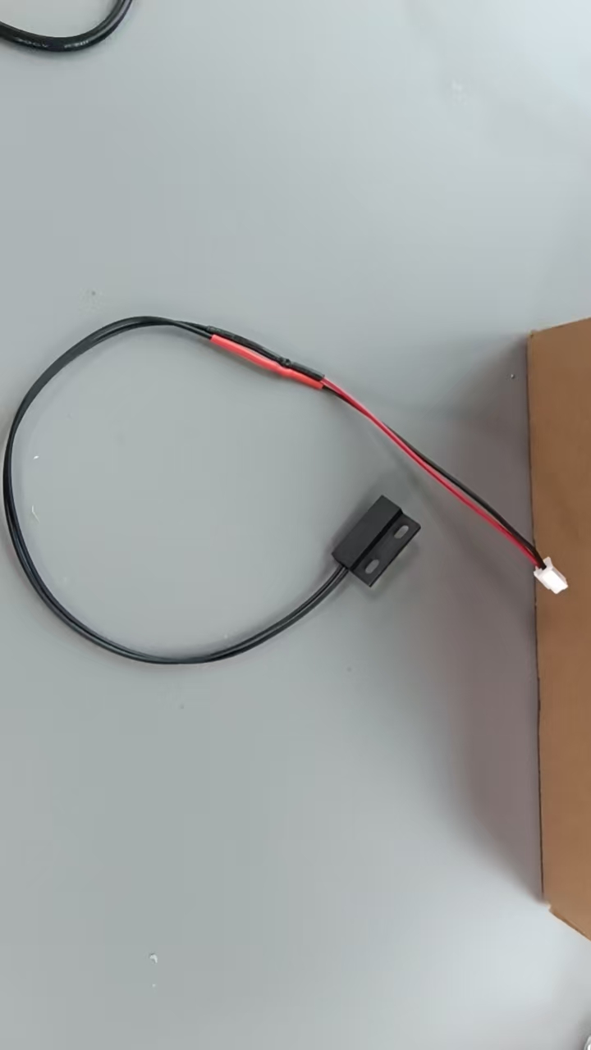
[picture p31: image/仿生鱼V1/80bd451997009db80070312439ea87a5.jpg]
80bd451997009db80070312439ea87a5


***

### 3.PCB主控

接下来就需要焊接PCB了

PCB上的元器件主要有 ：

双排母，15P , 2.54MM 间距 （一个板子需要两个）

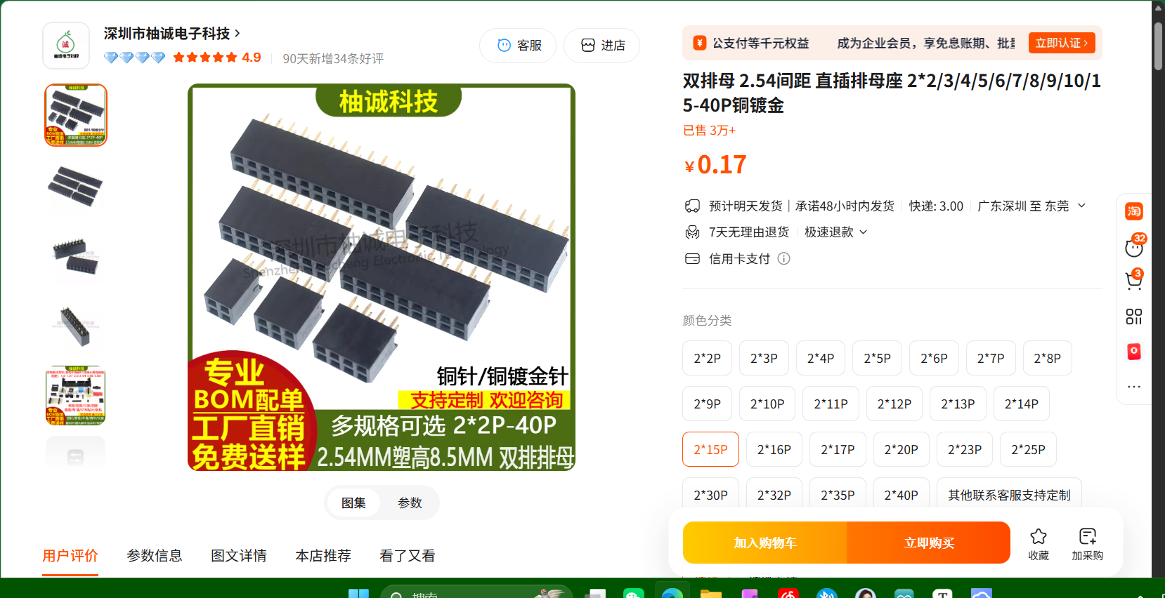
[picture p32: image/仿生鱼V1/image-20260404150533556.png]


弯针排母 ， 4P + 3P ，一个用于 蓝牙 ，一个用于 降压模块

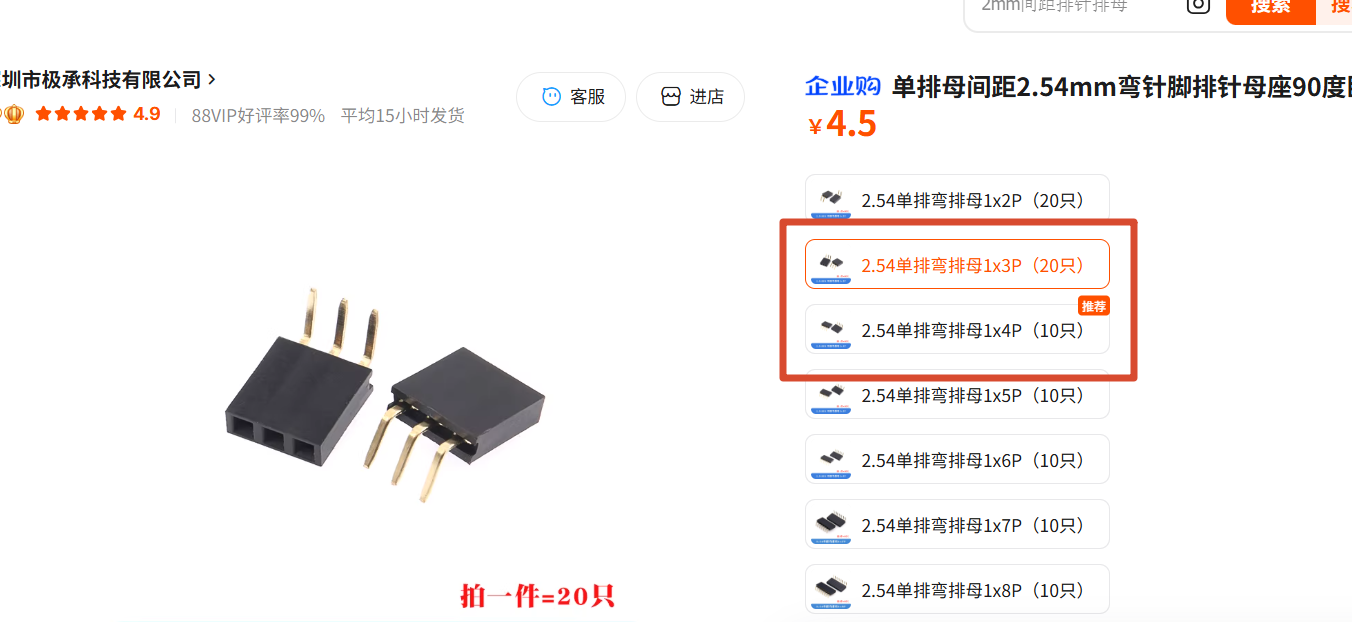
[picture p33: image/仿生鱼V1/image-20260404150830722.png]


排针 （用于连接舵机）

注意：无论排针排母，长的可以剪短，但是短的无法拼接变长（焊接间距不足）

所以，宁愿买长（更多P）也不要买短！！

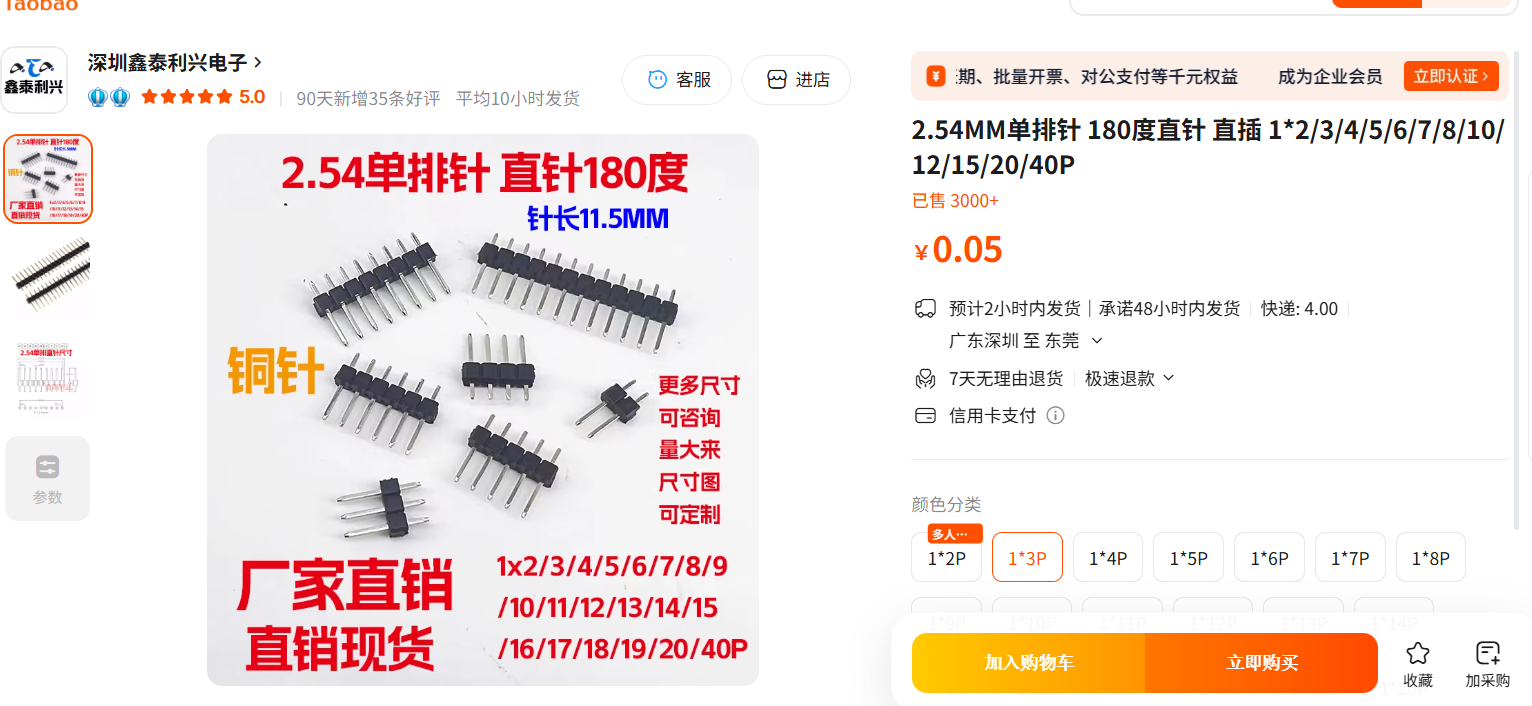
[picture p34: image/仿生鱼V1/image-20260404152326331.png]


胶壳接口 2P 直针 2.54MM 间距（前面有提到过）

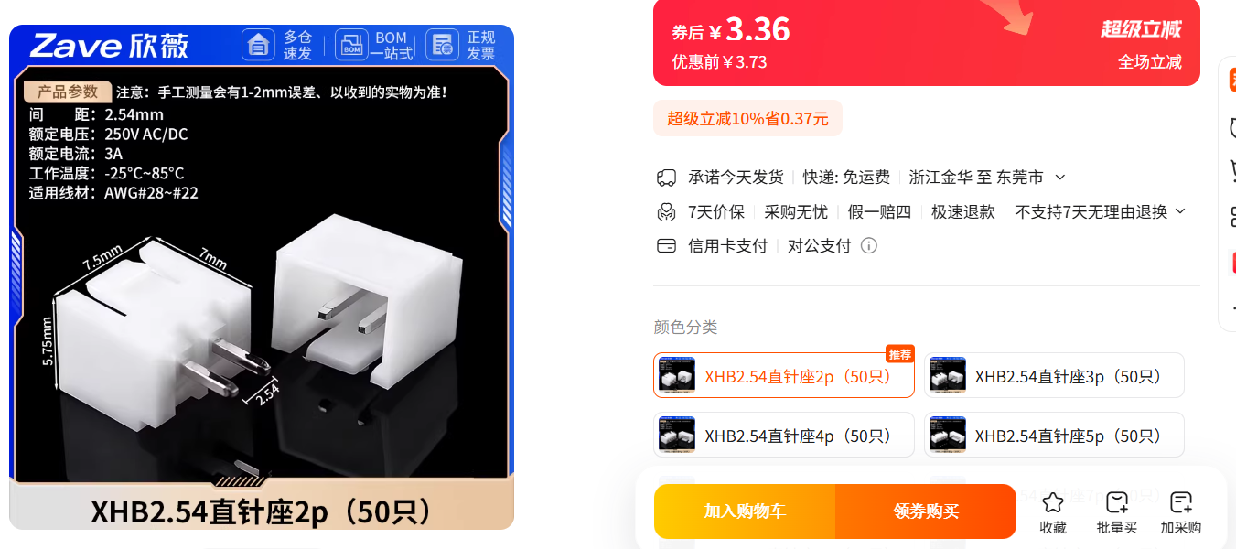
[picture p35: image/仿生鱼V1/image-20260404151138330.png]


降压模块：

**DC-DC 降压电源模块 5V 输出 短路保护**

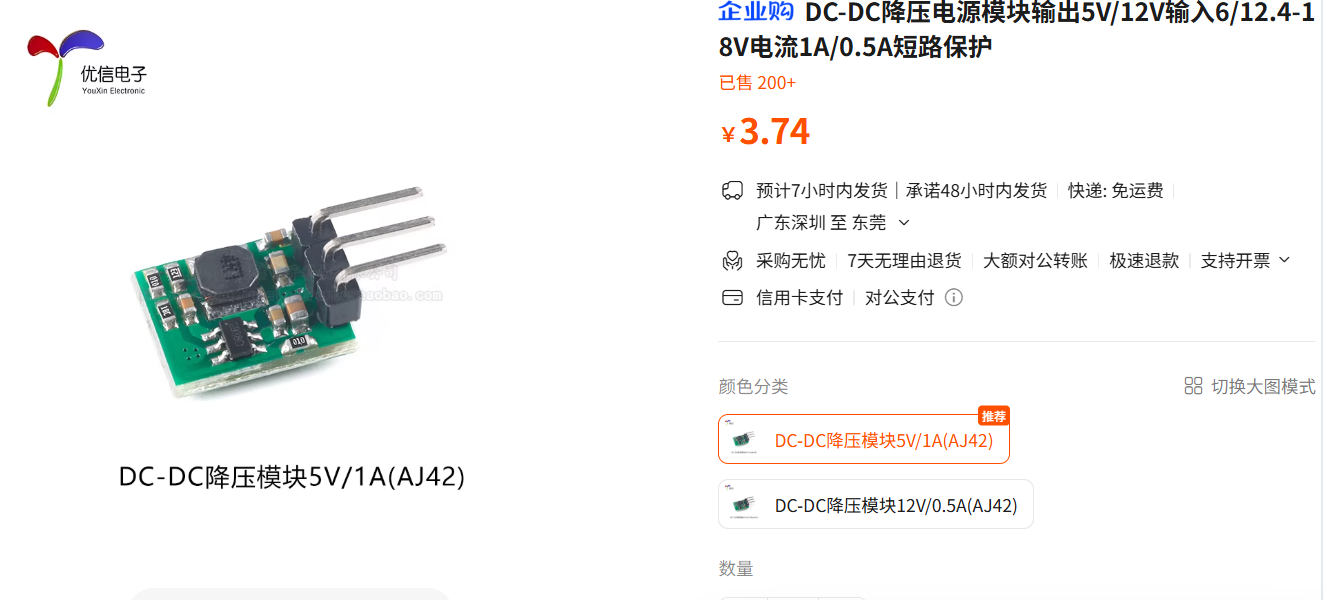
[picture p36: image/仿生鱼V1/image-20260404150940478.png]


继电器：

**宏发继电器 HF32F-G 005 常开 10A 4脚**

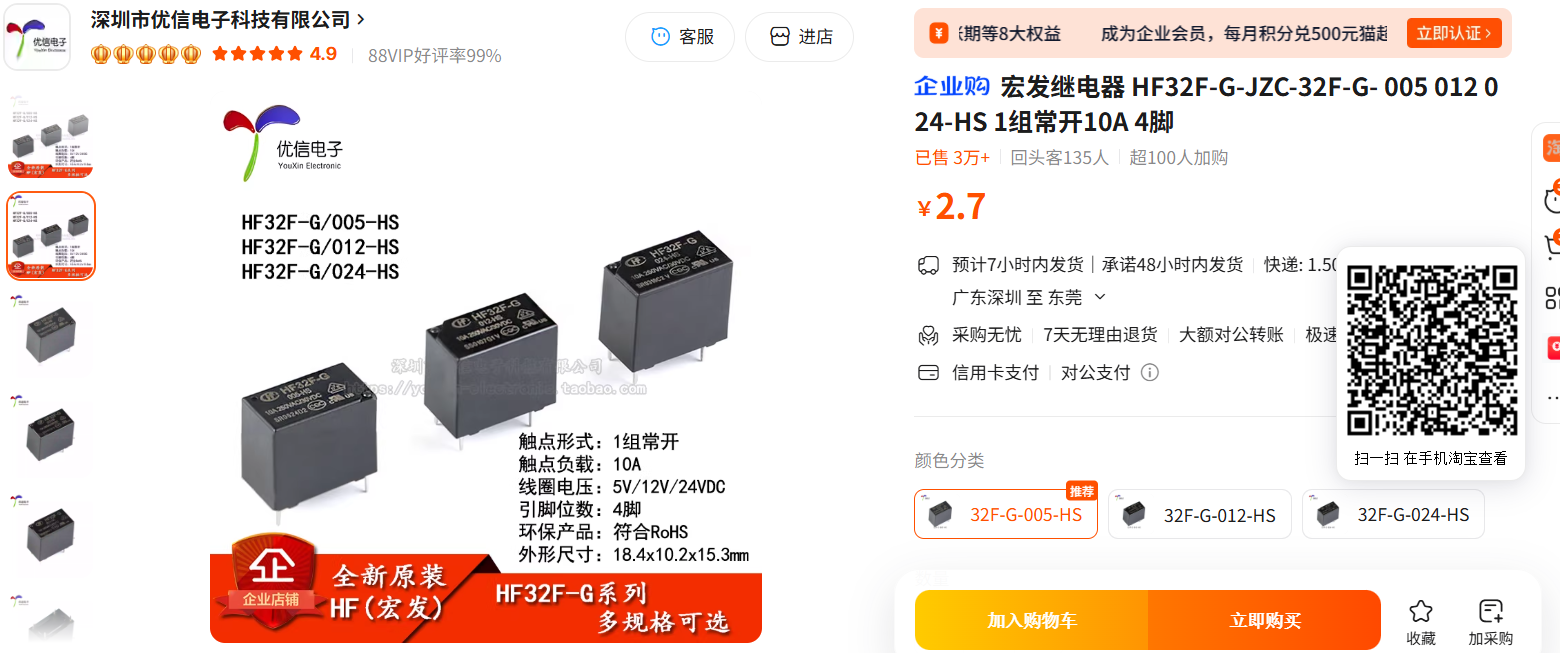
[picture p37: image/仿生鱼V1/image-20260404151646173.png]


蓝牙模块：

**DX-BT04-A/08-A 双模蓝牙模块 SPP3.0+BLE4.2 串口透传**

强烈建议选型 带有 BLE协议 的蓝牙，否则有一些设备可能无法进行连接

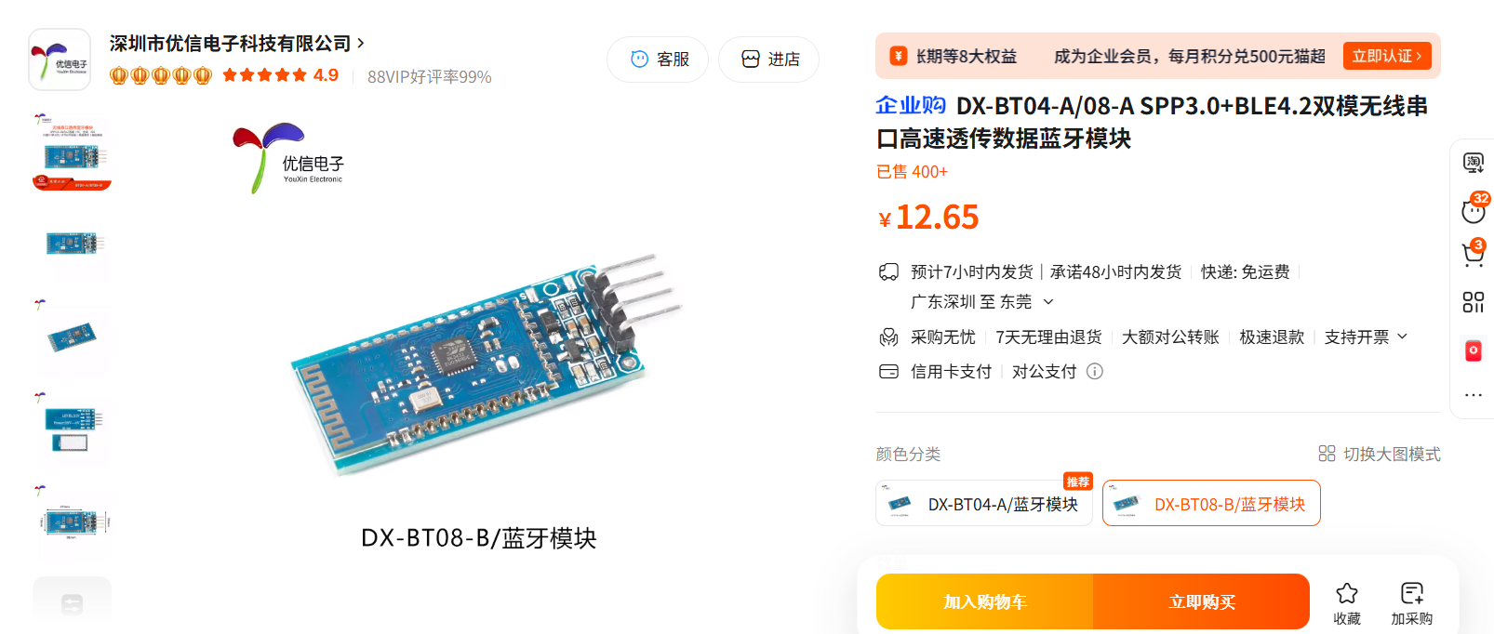
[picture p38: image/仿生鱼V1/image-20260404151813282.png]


arduino nano 主控板子

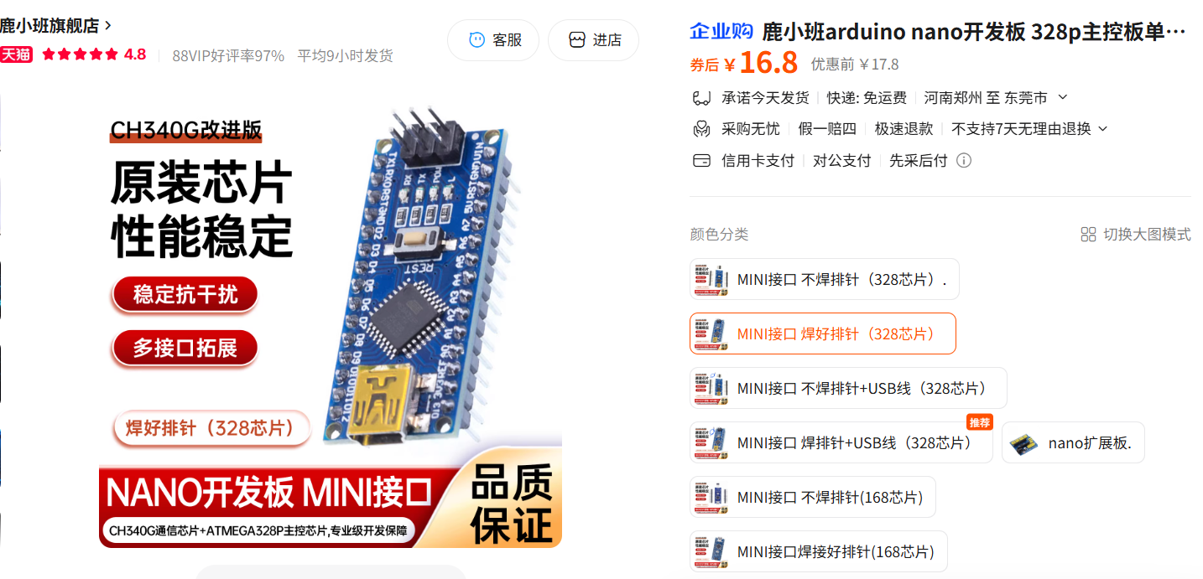
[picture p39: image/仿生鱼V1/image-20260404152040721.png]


### 4.电池

注意是 7.4 V 的 两排

**7.4V 锂电池 21700 大容量 充电电池组**

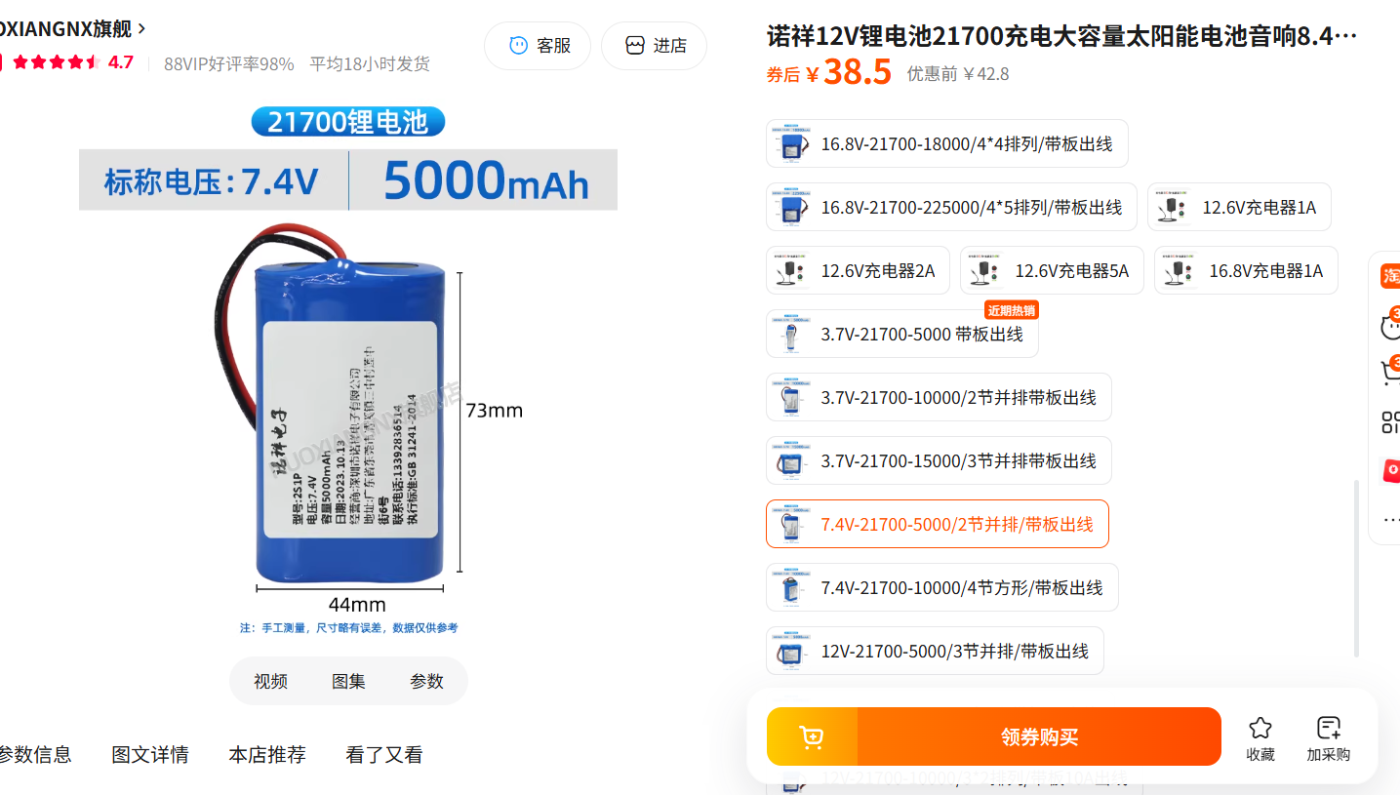
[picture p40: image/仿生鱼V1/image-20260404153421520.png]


商家支持定制引出的端子，就选择 XH 2.54 红黑

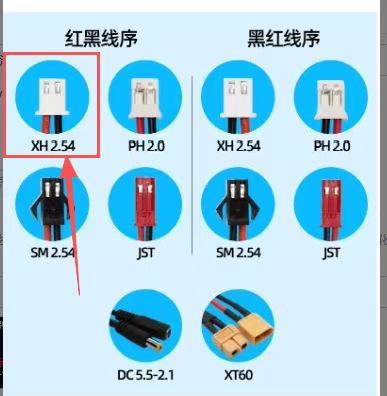
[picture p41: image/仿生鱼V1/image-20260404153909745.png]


### 5.防水舵机

**防水舵机 潜水 水下机器人 全金属外壳 IPX8**

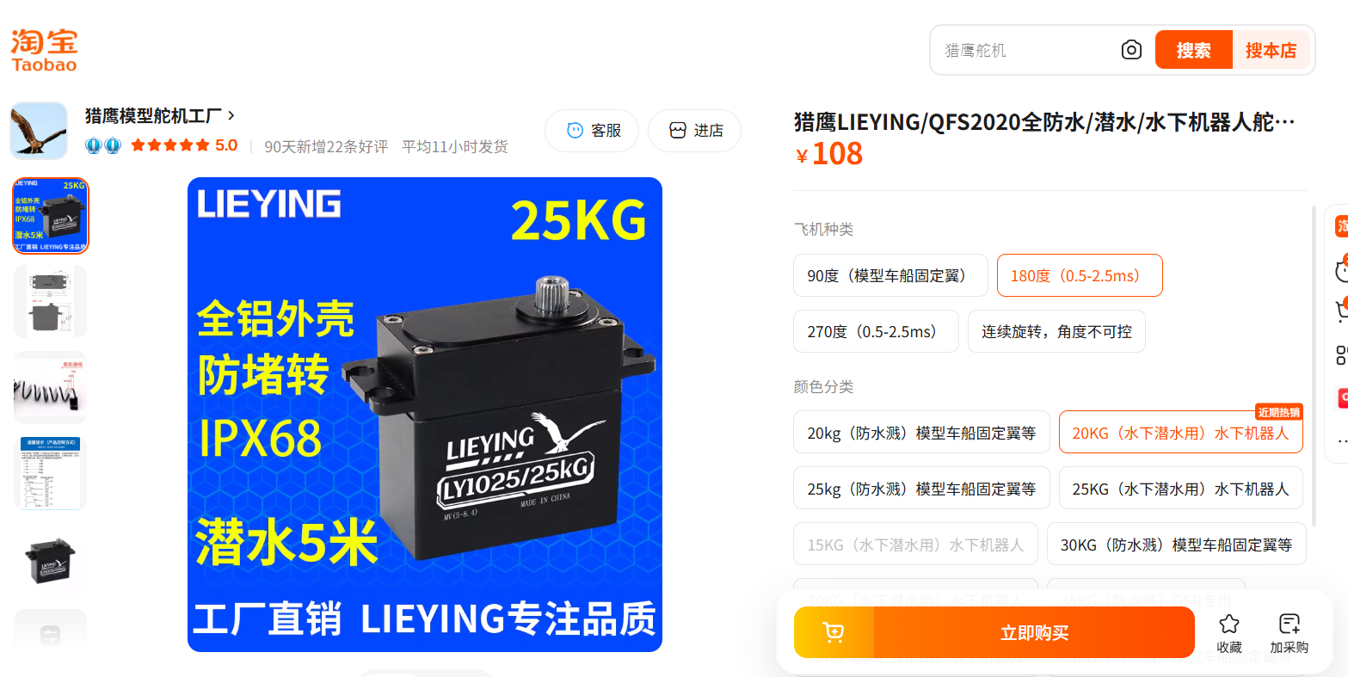
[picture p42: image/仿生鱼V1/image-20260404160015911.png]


舵机记得选 7.4~8.4V的，防水的，PWM舵机

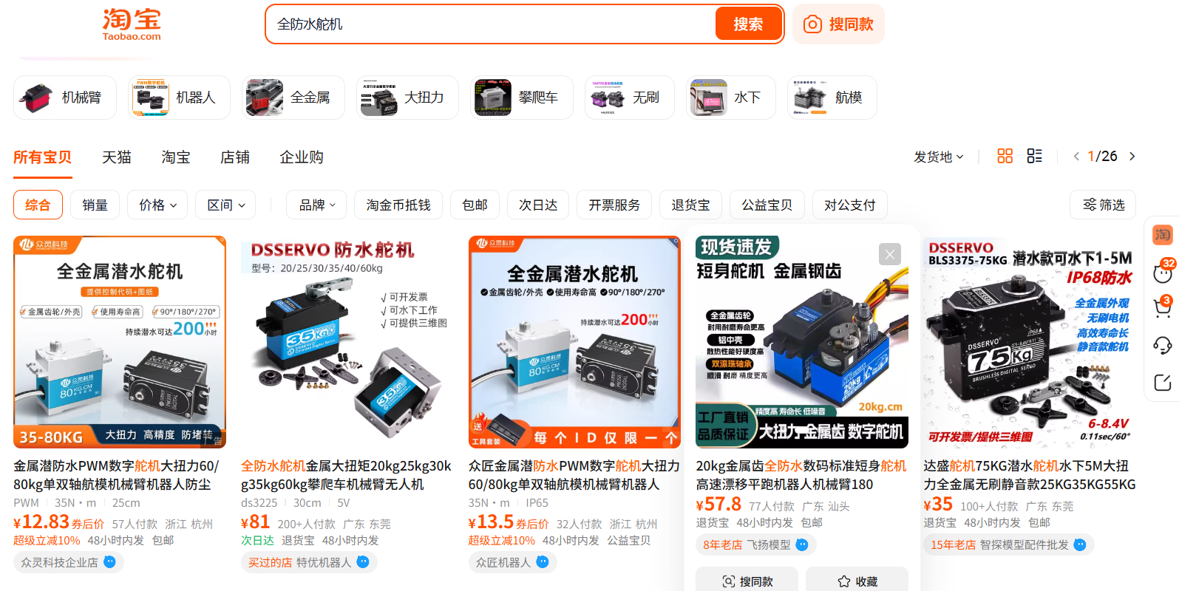
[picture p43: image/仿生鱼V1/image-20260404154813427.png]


### 6.充电器

注意是7.4V的充电器，不能用12V充电器充电！！

**7.4V 锂电池充电器 通用**

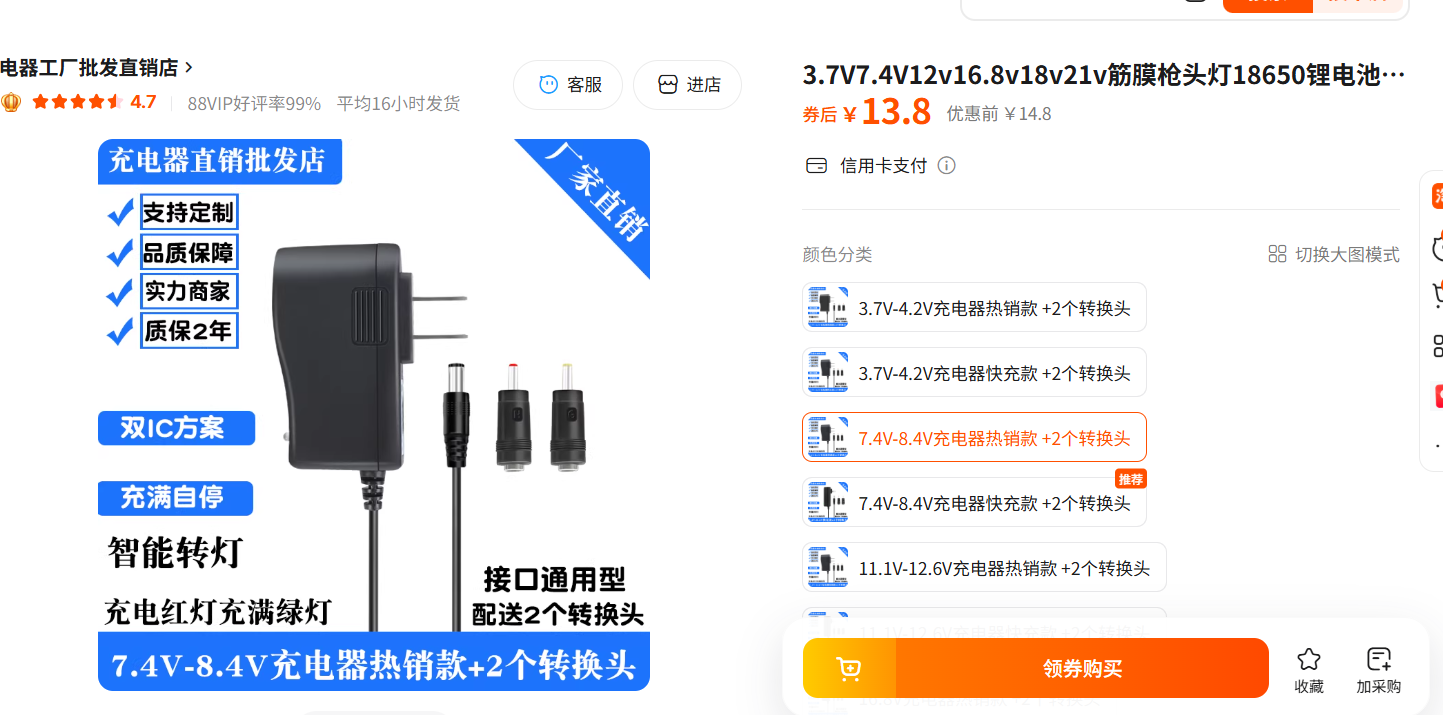
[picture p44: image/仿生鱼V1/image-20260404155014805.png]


### 7.磁铁

直径10mm，厚度3mm 

这个需要根据机械结构的设计微调

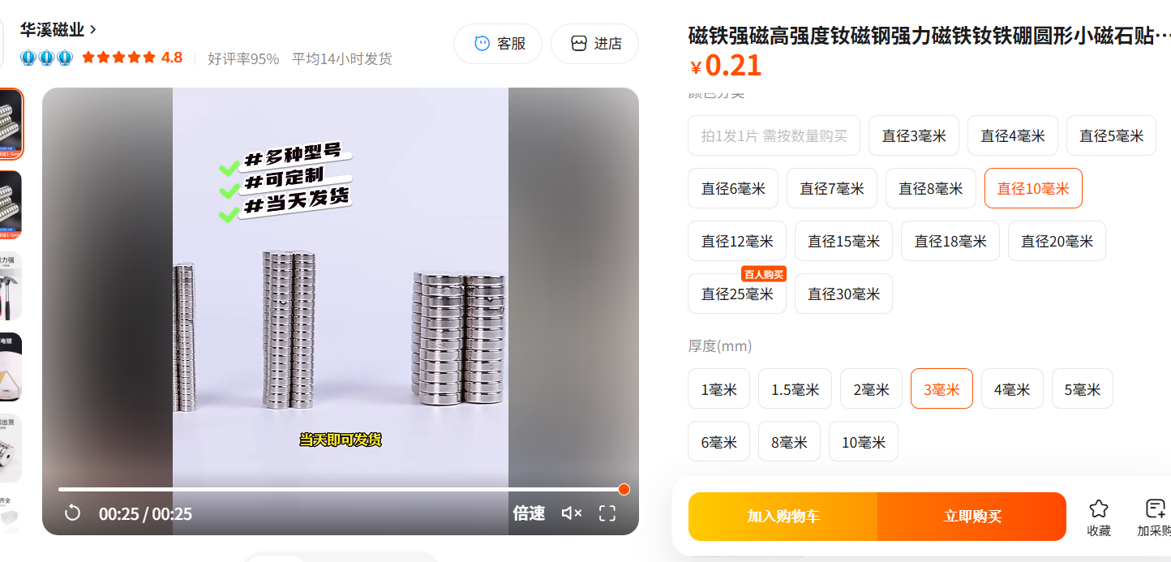
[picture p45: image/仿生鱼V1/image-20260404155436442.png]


### 8.密封垫圈

**食品级硅胶垫圈 平垫圈 密封圈 定做 2mm**

这个需要后面微调 加厚 （目前旧鱼的结构适配）

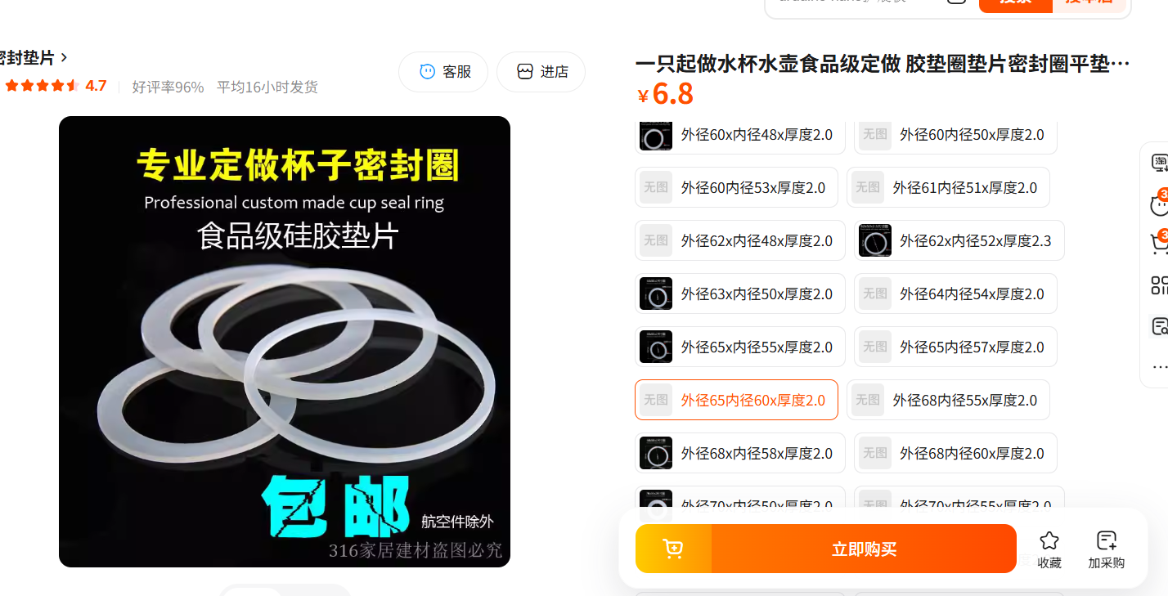
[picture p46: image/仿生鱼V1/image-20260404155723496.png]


### 9.M3螺丝螺母

这主要是在鱼尾那边需要

需要短的，也需要长的

需要平头的，也需要弓头的（鱼尾）

### 10.防水胶

热熔胶，502胶水（粘磁铁），电工胶布，生料带

### 11.其他

电烙铁，热风枪，热缩管，镊子，电工钳

***

# 焊接PCB

正面

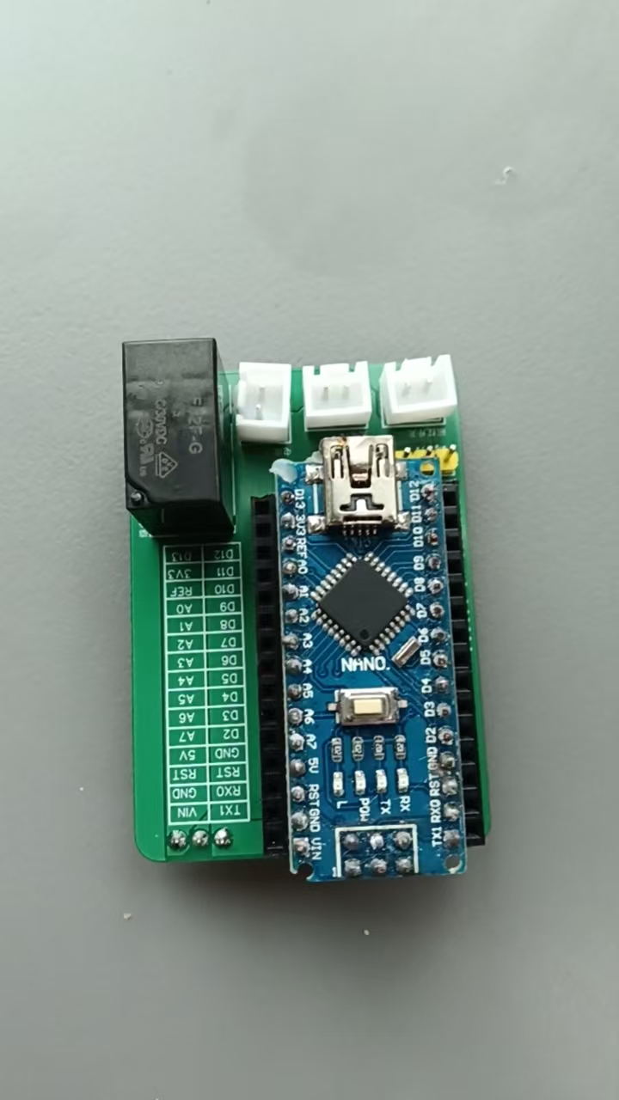
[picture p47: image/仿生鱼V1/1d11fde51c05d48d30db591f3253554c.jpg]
1d11fde51c05d48d30db591f3253554c


背面

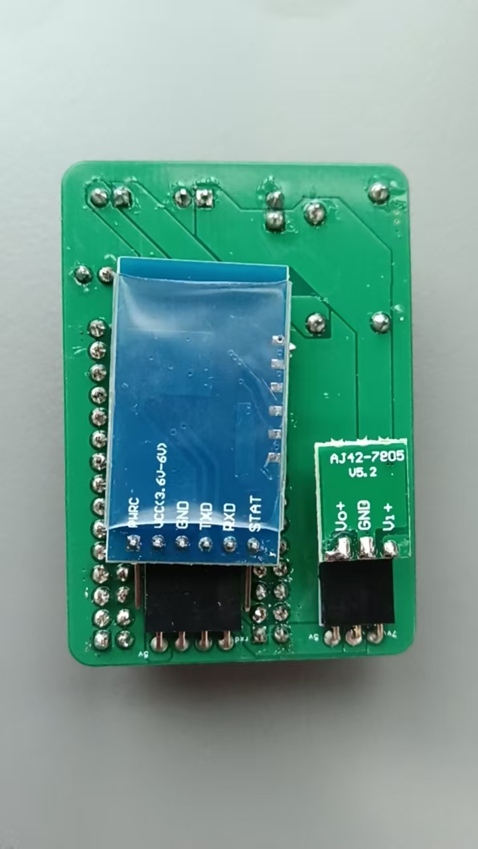
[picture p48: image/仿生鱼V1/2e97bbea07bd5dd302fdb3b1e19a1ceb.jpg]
2e97bbea07bd5dd302fdb3b1e19a1ceb


建议先焊接高度低的（排针排母），最后再焊接高的（继电器）

这一步其实没什么难的

还是那句话：配件一定要提前备齐，就不会有各种 麻烦事  

焊接好后就能直接上电测试

建议在PCB底面贴一层电工胶布作为做绝缘处理，如下：

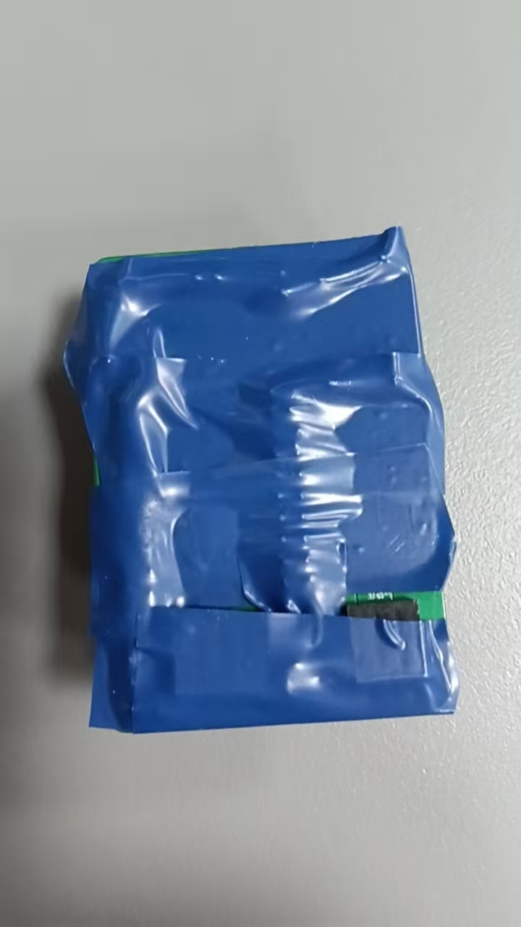
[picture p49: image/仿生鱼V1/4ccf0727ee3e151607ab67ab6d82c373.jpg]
4ccf0727ee3e151607ab67ab6d82c373


# 安装充电口/磁控开关

最简单的方法依旧是用热熔胶

磁控开关记得磁性接口朝上

充电口记得从上向下穿过

***

# 充电口测试

根据PCB的 丝印指示 ，在对应的地方插上对应的接口

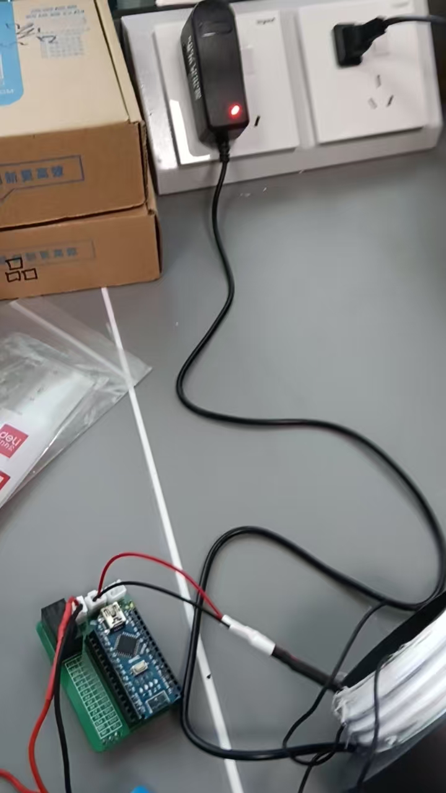
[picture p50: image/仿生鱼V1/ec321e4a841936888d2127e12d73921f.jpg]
ec321e4a841936888d2127e12d73921f


如果充电器从 绿灯变成 红灯  表示正在充电

如果没有变化，说明接线有问题（某部分没有连接好）

如果充电器 的灯 熄灭 且 电线发烫 请**立刻切断电源**！！！

# 测试舵机

现在，把舵机给安装到鱼尾上

这里我们用是热熔胶 + 螺丝   ，其他的防水胶 需要额外考虑

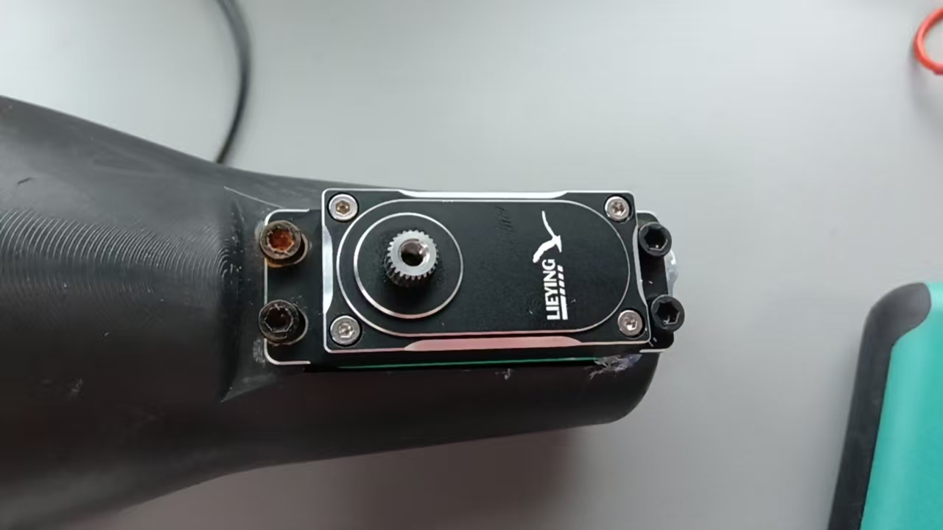
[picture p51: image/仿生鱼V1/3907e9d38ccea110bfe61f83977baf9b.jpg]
3907e9d38ccea110bfe61f83977baf9b
  

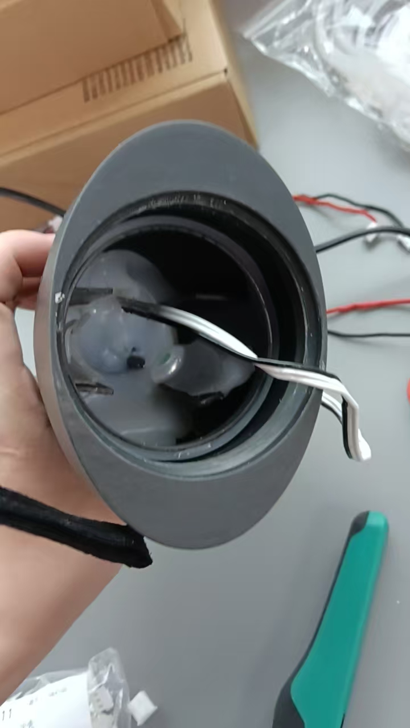
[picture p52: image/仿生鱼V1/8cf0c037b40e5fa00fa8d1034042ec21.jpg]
8cf0c037b40e5fa00fa8d1034042ec21


电脑上 安装 arduino IDE

官网链接：[arduino.cc/en/software/](https://www.arduino.cc/en/software/) 

安装后打开小鱼的控制程序（见仓库 `Code/fish/fish.ino`）：

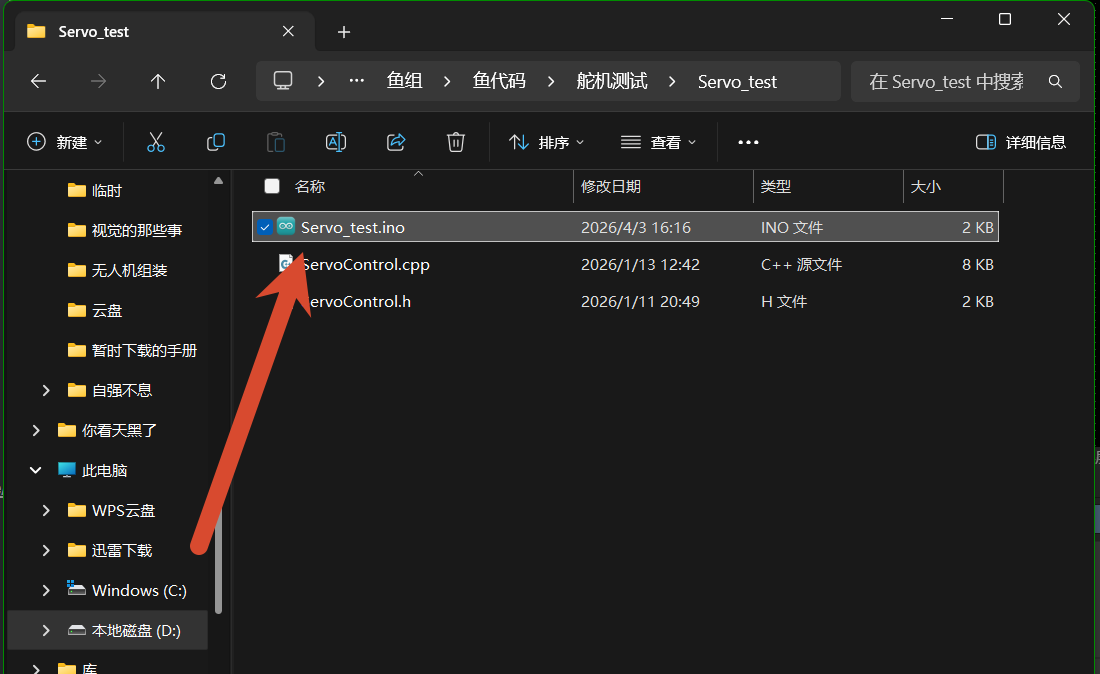
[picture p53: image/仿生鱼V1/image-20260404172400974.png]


先在工具，把开发板选择 Arduino Nano 并选择好对应 端口

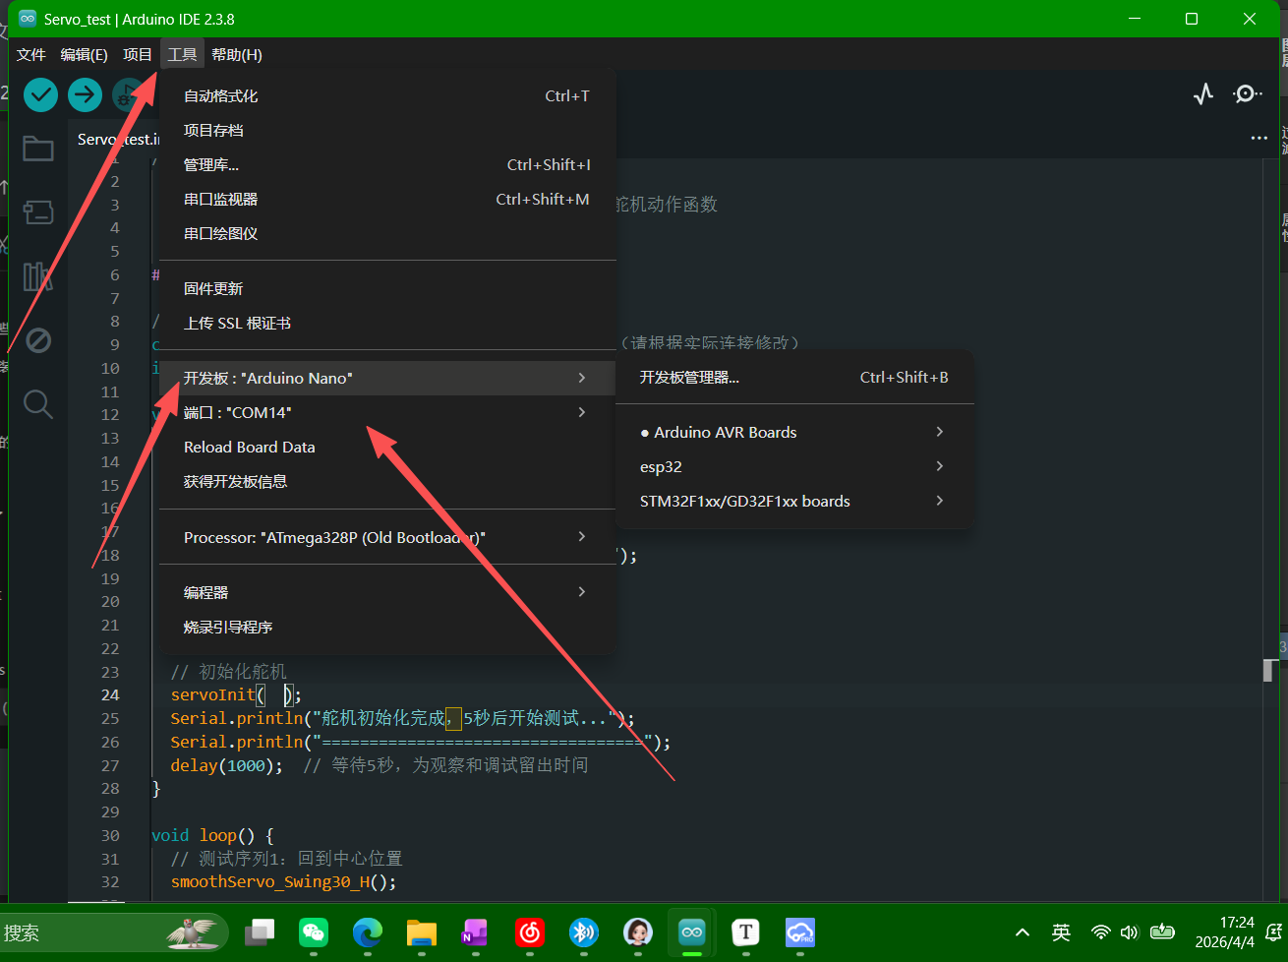
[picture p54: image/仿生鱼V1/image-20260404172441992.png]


端口怎么选择？

先把arduino 连上电脑

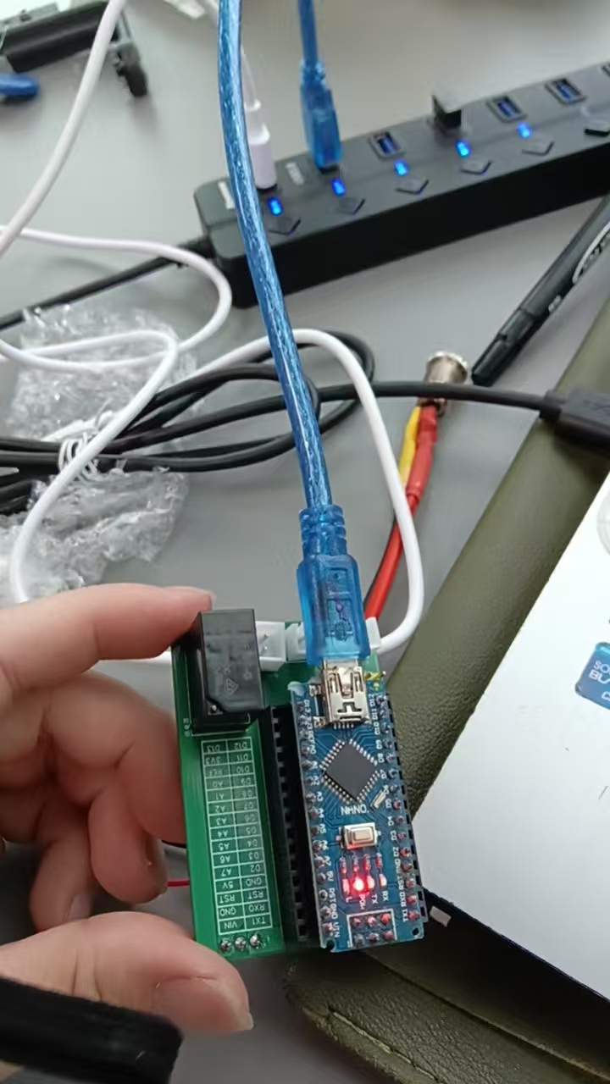
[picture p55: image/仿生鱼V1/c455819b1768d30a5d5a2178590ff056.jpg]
c455819b1768d30a5d5a2178590ff056


打开电脑的设备管理器

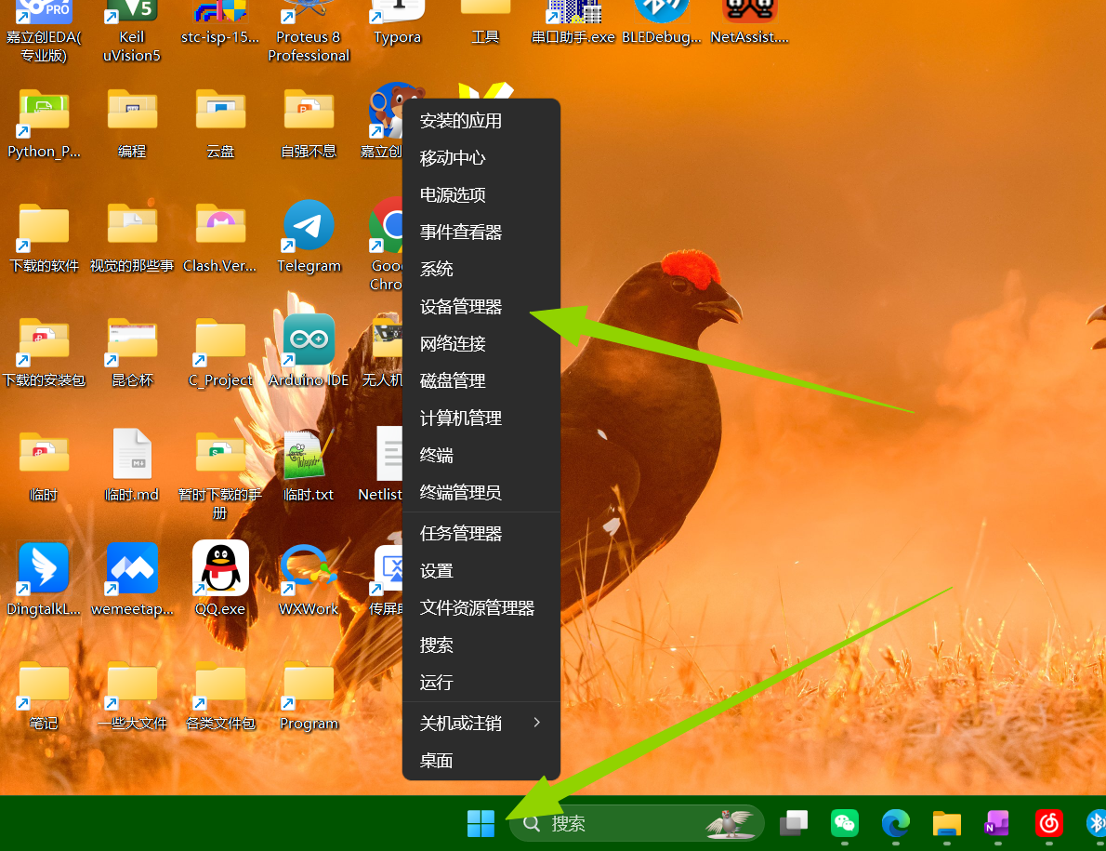
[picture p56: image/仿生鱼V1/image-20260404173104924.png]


这个显示的就是端口号

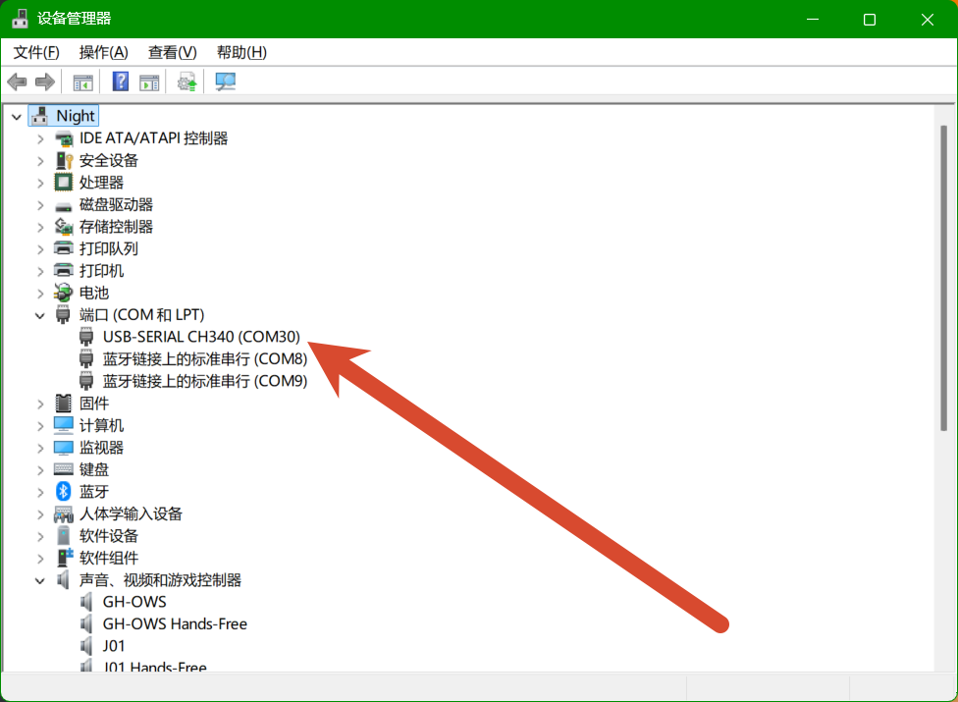
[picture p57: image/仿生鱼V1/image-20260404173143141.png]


回到arduino IDE ，选好芯片还有端口号 点击 烧录

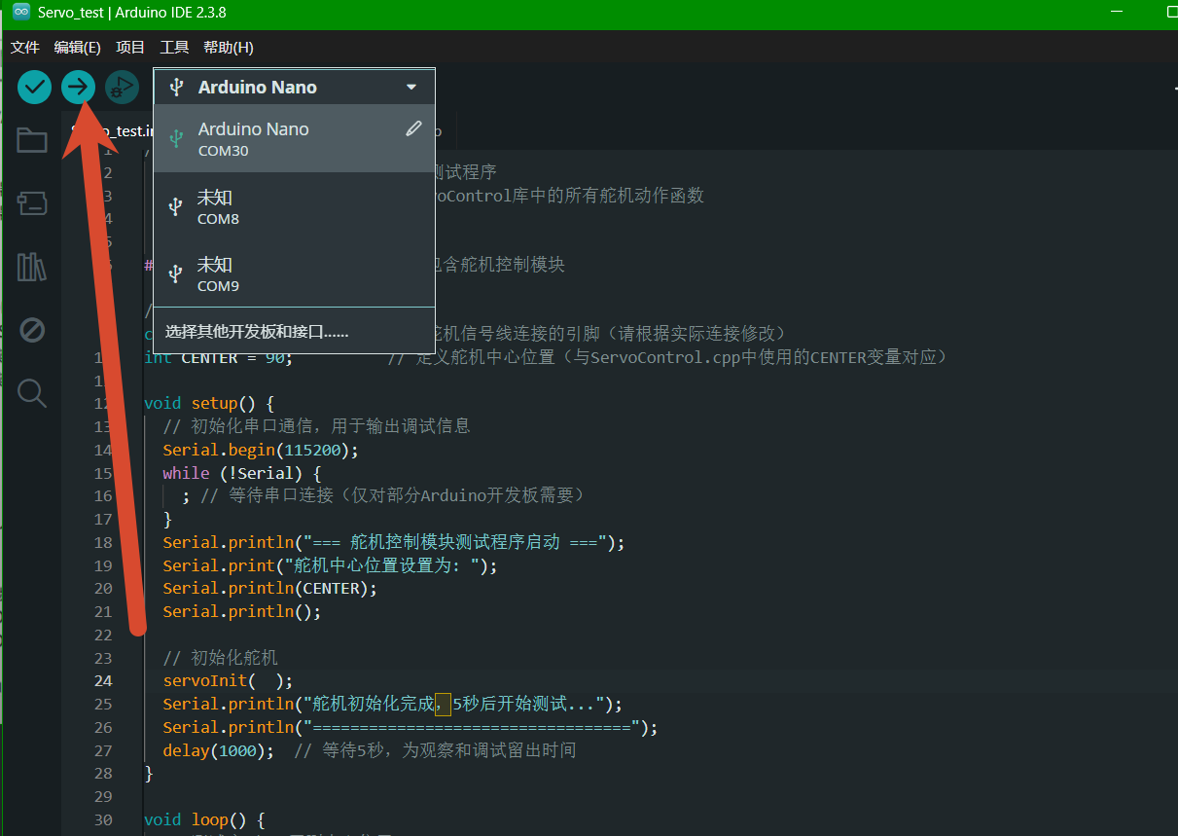
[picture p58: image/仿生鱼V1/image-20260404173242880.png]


**常见错误：**

> 端口号不正确：
>
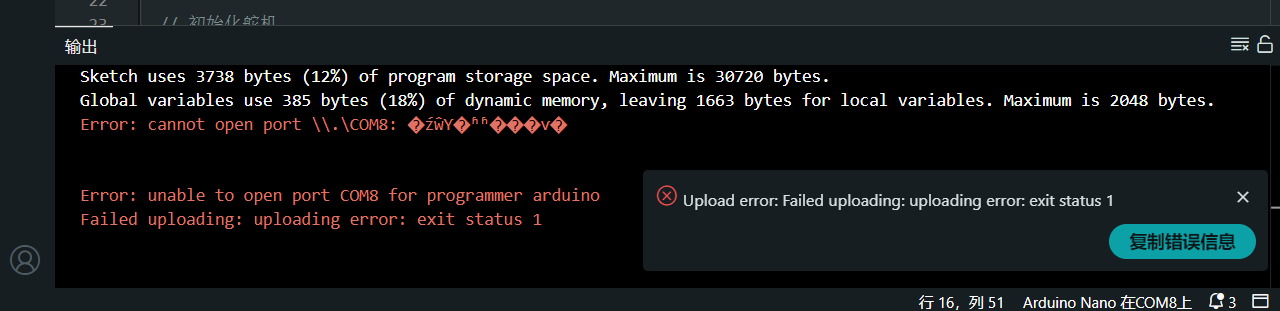
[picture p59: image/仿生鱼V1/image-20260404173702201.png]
> 
>
> 遇到这种错误，那就先把蓝牙模块给拔掉，烧录的时候不占用tx和rx引脚
>
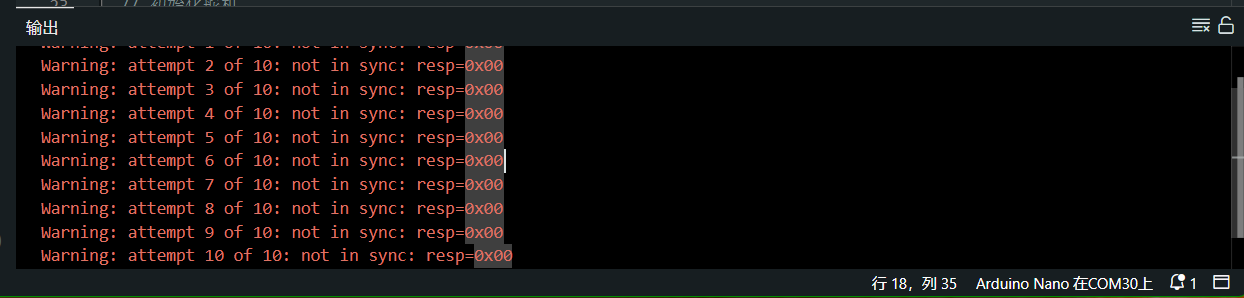
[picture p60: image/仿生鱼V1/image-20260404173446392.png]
> 

最终会成功如图示：

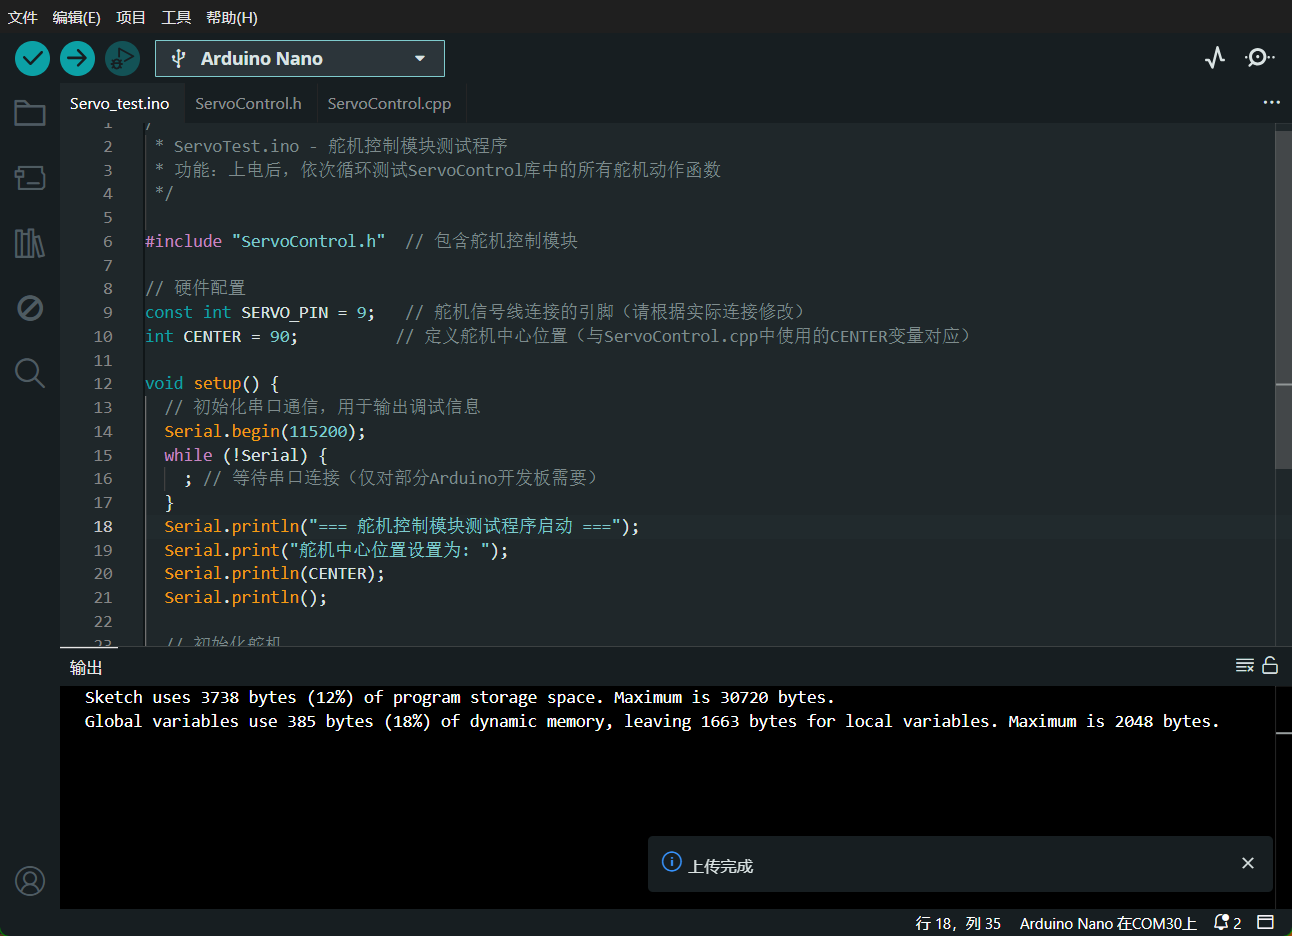
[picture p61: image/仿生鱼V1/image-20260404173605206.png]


此时 测试舵机的代码 已经成功烧录到 单片机里面

舵机引出来一般有三根线

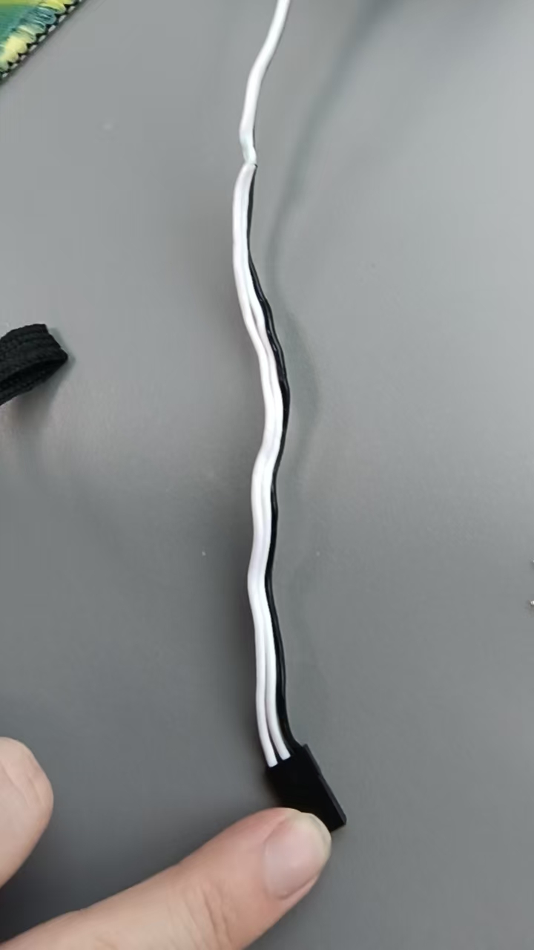
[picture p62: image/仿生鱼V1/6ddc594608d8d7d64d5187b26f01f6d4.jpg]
6ddc594608d8d7d64d5187b26f01f6d4


黑色的 那一根是 GND

中间那一 根 是 VCC

最左边那一个根是信号线 

根据PCB板 丝印  提示 插上去即可 

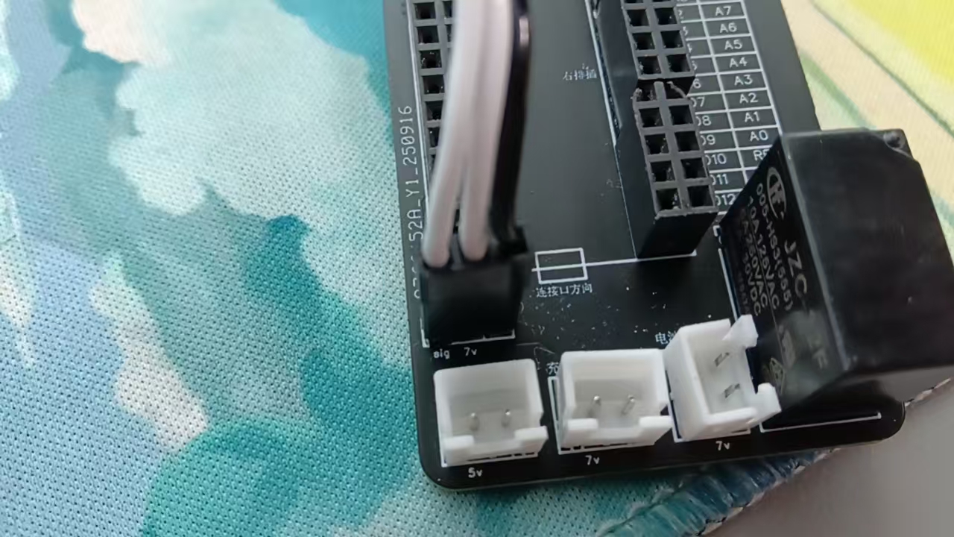
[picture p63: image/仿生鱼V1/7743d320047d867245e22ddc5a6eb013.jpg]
7743d320047d867245e22ddc5a6eb013


插入 电源 磁控开关 还有舵机线

然后 磁铁靠近 鱼顶 ，此时 舵机会不断地 响动

说明舵机正常

<video src="../image/仿生鱼V1/ServoTest.mp4" controls width="100%"></video>

# 蓝牙测试

在板子 背面插上蓝牙 同时 ，给 arduino IDE 烧录 这一份代码：

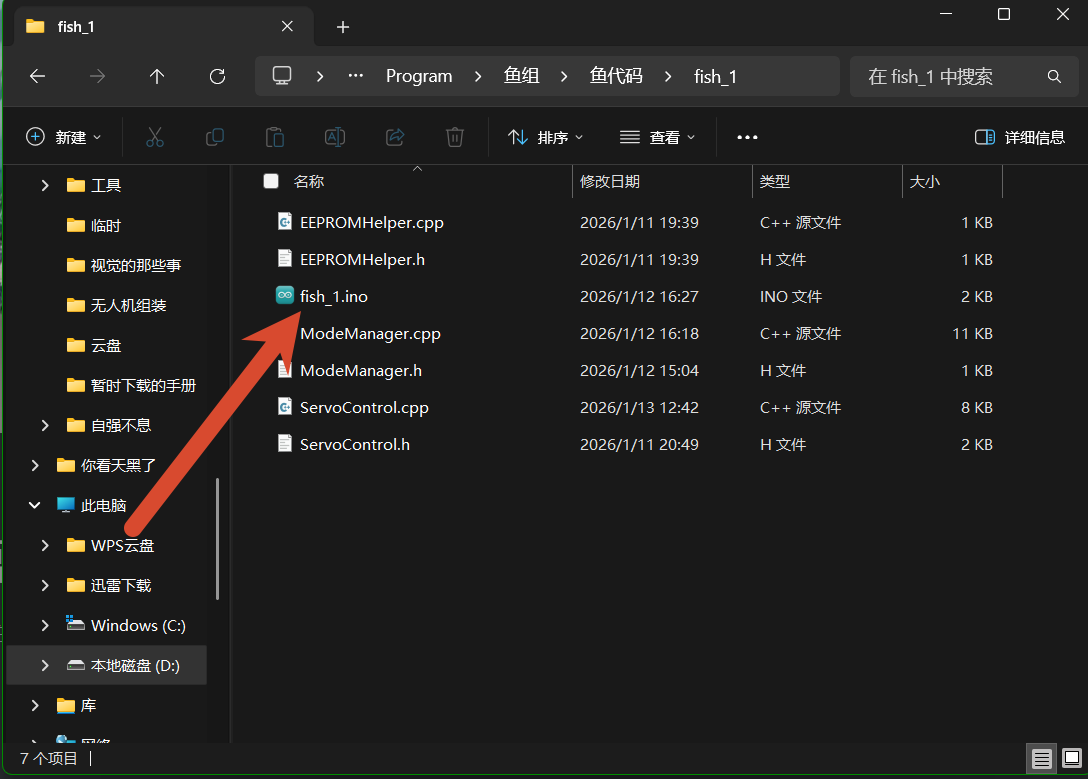
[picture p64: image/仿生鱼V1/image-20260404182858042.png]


同理，记得选择好端口 和 板子类型 （建议把 arduino Nano 拔下来烧录）

接着，手机安装 蓝牙调试器（安装包已随仓库提供：`软件/蓝牙调试器_v1.95.apk`，该软件来自第三方网络，版权归原作者所有）

进入蓝牙调试器，连接对应的蓝牙

在发送区发送对应的指令 比如 CMD_a / CMD_b / CMD_A 等

更多指令详见于 指令说明文档

如果鱼正常运行，说明电控模块正常。

***

# 配重

鱼的内嵌模块正常之后，就是调配重环节

给电路模块打上热熔胶

然后包裹上一层塑料密封袋，再配上一些包一些面巾纸做防水

在水盆里面调整一下配重

***

# 密封检查

配重完成之后，密封鱼的旋钮处

然后装上磁铁 

注意，磁铁一定一定要注意方向！！！

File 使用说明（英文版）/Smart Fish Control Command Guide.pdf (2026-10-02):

Command | Function Description
CMD_S | Servo returns to the center position
CMD_R | Servo swings continuously to the right
CMD_L | Servo swings continuously to the left
CMD_a | ±15° swing (low speed)
CMD_A | ±15° swing (high speed)
CMD_b | ±30° swing (low speed)
CMD_B | ±30° swing (high speed)
CMD_c | ±45° swing (low speed)
CMD_C | ±45° swing (high speed)

# Smart Fish Control Command Guide

The smart fish features three operation modes: Basic Mode, Center Calibration Mode, and Custom Mode.
Upon power-on, the smart fish automatically enters Basic Mode.

## 1. Basic Mode (Default Mode)

Basic Mode is the default swimming mode, designed for direct control of the fish's movement.
Sending CMD_D or CMD_E to the fish allows entry into the other two debugging modes.

Function: Execute preset actions (center return, left/right rotation, fixed-amplitude swing); Entry Method: Automatically entered after system power-on, or return by sending X in other modes.

This mode is used to calibrate the servo's center position.
Although the servo's center position is pre-calibrated to 90 degrees,
deviations may occur over time. This mode is therefore used to determine the exact servo angle when the fish's tail is at the center position.

## 2. Center Calibration Mode

Function: Customize the servo's center position (the default center can be calibrated via this mode);
Entry Method: Send CMD_D in Basic Mode.

Operation; Function Description; Restrictions

Input a number ( CMD_0 - CMD_180 ) | Set the current servo angle as the new center | The angle must be within the range of 0-180 degrees; an error prompt will be issued if the range is exceeded
Send CMD_X | Return to Basic Mode | Residual input will be cleared before exiting to avoid interference

Operation; Function Description; Example:

Send parameters (e.g., 70,110,20 ) | Swing cyclically according to the set angles and delay until a new command is sent
Send X | Return to Basic Mode and stop the current swing

Note: The set angle will be stored in the flash memory of the main control chip, and the center angle will remain as the last set value upon next power-on.

Once the fish's center angle is determined, the swing can be controlled based on this position.
In this mode, you can set the servo to swing continuously between two specified angles. "Delay" can be understood as the number of milliseconds of delay per degree of servo movement. A larger value results in slower tail swing speed.

## 3. Custom Mode

Function: Freely set the angle range of servo swing and the per-step delay time; Entry Method: Send CMD_E in Basic Mode.

### Input Format 1

Note that three parameters separated by commas must be sent: CMD_Angle1,Angle2,Delay(ms)

Angle1/Angle2: The two endpoint angles of the servo swing (e.g., 70 and 110; the servo will swing back and forth between 70° and 110°);
Delay(ms): The per-step interval time for the servo to move from one angle to another (affects swing speed).

### Parameter Restrictions

Angle: 0-360 degrees (an error prompt will be issued if the range is exceeded);
Delay: 1-1000ms (an excessively small value may cause servo jamming, while an excessively large value will reduce response speed).

### Operation Commands

Sending CMD_70,110,20 → The serial port displays "✅ Custom swing: 70° ↔ 110°, delay 20ms", and the servo starts swinging back and forth;
Sending CMD_0,180,500 → The servo swings slowly between 0° and 180°, with a per-step interval of 500ms.

Operation; Function Description

Send parameters (e.g., CMD_70,110,20,3,2000 ) | Swing between 70° and 110° with a per-step delay of 20ms (controlling speed); after 3 swing cycles, pause for 2 seconds, then resume swinging for 3 cycles, and repeat
Send CMD_X | Return to Basic Mode and stop the current swing

### Input Format 2

Comparison with real fish: A real fish's tail does not swing continuously; after a few swings, the fish pauses to rest.
Custom Mode supports simulating the fish's pause time.

Note that five parameters separated by commas must be sent:

CMD_Angle1,Angle2,Delay(ms),Swing Cycles,Pause Duration
Angle1/Angle2: The two endpoint angles of the servo swing (e.g., 70 and 110; the servo will swing back and forth between 70° and 110°);
Delay(ms): The per-step interval time for the servo to move from one angle to another (affects swing speed);
Swing Cycles: The number of cycles the servo swings;
Pause Duration: The pause time (in ms) after completing N cycles (where N is the previous parameter).

### Operation Commands

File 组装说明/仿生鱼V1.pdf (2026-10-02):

本篇旨在 带新手 从0到1组装 出一条仿生鱼

所有步骤经过 大量的摸索与试错

当然，没有标准答案，如果有更优雅的组装方法 / 方案 欢迎指正提出

注意：下文给出的均为淘宝搜索关键词而非固定店铺链接，按关键词搜到同类商品即可，不必拘泥于示 例店铺

# 配件准备

打印完鱼后，先准备一下基本部件：

## 1.电池充电口

这个需要注意方向外壳 （外边长条是 GND ，内条是 7.4V）


如图所示，外壳长条需要接黑线（GND），內部短条 接 红线 （VCC）

该接口淘宝搜索关键词（与防水帽一并购买）：
DC电源插座 DC-099 5.5*2.1 充电插座 母座 带防水帽

线的另一端需要接 接线端子

接线端子的 方向如下（插入 左边正 ，右边负）

特别注意，端子是有方向的


端子线淘宝搜索关键词：XH2.54 2P 单头连接端子线 22AWG 红黑电源线

这里需要注意 左红右黑、22AWG（线径）、200mm（长度）

最终预期效果


图为拼装线，故略微有瑕疵（此即为线材买错的下场）

一定一定注意方向，千万千万不要接反

这里再顺便提一下 PCB上的 胶壳接口

胶壳母座接口（焊在PCB上的）淘宝搜索关键词：

XH2.54 直针 插头插座 接线端子

注意是 2P（两根线） ，间距 2.54mm 直针的 ！！！

## 2.磁控开关

淘宝搜索关键词：

GPS-23 磁控开关 常开常闭 干簧管 门磁开关


由于这个末端 为铜丝线

为了 可拆卸方便 这个需要我们自己装上 接线端子 （强烈不建议直接焊接在PCB上）

（如果能找到支持 定做 接线端子的 商家 是最好的 ）

装上接线端子 有两种方法：

1.机械做法：买端子壳 + PH2.54端子针

需要用到的工具 ： 压线钳
XH2.54 接插件连接器 端子插头 直针/弯针 2P/3P/4P


具体操作教程示例视频：【教程】XH2.54端子压线，三种方法教你入门哔哩哔哩bilibili (https://www.bilibili.com/video/BV1fGRmYrEZJ/)

2.电工做法：把线剪短一些 + 焊接之前买的 端子线

需要用到的工具：焊笔+热风枪

（本质上就是把两根线焊接在一起）

这里采用第二种方法，最终效果如图：


## 3.PCB主控

接下来就需要焊接PCB了

PCB上的元器件主要有 ：

双排母，15P , 2.54MM 间距 （一个板子需要两个）

弯针排母 ， 4P + 3P ，一个用于 蓝牙 ，一个用于 降压模块

排针 （用于连接舵机）

注意：无论排针排母，长的可以剪短，但是短的无法拼接变长（焊接间距不足）

所以，宁愿买长（更多P）也不要买短！！


胶壳接口 2P 直针 2.54MM 间距（前面有提到过）

降压模块：

DC-DC 降压电源模块 5V 输出 短路保护

继电器：

宏发继电器 HF32F-G 005 常开 10A 4脚


蓝牙模块：
DX-BT04-A/08-A 双模蓝牙模块 SPP3.0+BLE4.2 串口透传

强烈建议选型 带有 BLE协议 的蓝牙，否则有一些设备可能无法进行连接

arduino nano 主控板子

4.电池


注意是 7.4 V 的 两排

7.4V 锂电池 21700 大容量 充电电池组

商家支持定制引出的端子，就选择 XH 2.54 红黑

## 5.防水舵机

防水舵机 潜水 水下机器人 全金属外壳 IPX8


舵机记得选 7.4~8.4V的，防水的，PWM舵机

## 6.充电器

注意是7.4V的充电器，不能用12V充电器充电！！

7.4V 锂电池充电器 通用


7.磁铁

直径10mm，厚度3mm

这个需要根据机械结构的设计微调

## 8.密封垫圈

食品级硅胶垫圈 平垫圈 密封圈 定做 2mm

这个需要后面微调 加厚 （目前旧鱼的结构适配）


## 9.M3螺丝螺母

这主要是在鱼尾那边需要

需要短的，也需要长的

需要平头的，也需要弓头的（鱼尾）

## 10.防水胶

热熔胶，502胶水（粘磁铁），电工胶布，生料带
11.其他

电烙铁，热风枪，热缩管，镊子，电工钳

# 焊接PCB

正面

背面


建议先焊接高度低的（排针排母），最后再焊接高的（继电器）

这一步其实没什么难的

还是那句话：配件一定要提前备齐，就不会有各种 麻烦事

焊接好后就能直接上电测试

建议在PCB底面贴一层电工胶布作为做绝缘处理，如下：


# 安装充电口/磁控开关

最简单的方法依旧是用热熔胶

磁控开关记得磁性接口朝上

充电口记得从上向下穿过

# 充电口测试

根据PCB的 丝印指示 ，在对应的地方插上对应的接口


如果充电器从 绿灯变成 红灯 表示正在充电

如果没有变化，说明接线有问题（某部分没有连接好）

如果充电器 的灯 熄灭 且 电线发烫 请立刻切断电源！！！

# 测试舵机

现在，把舵机给安装到鱼尾上

这里我们用是热熔胶 + 螺丝 ，其他的防水胶 需要额外考虑


电脑上 安装 arduino IDE

官网链接：arduino.cc/en/software/

安装后打开小鱼的控制程序（见仓库 Code/fish/fish.ino ）：

先在工具，把开发板选择 Arduino Nano 并选择好对应 端口


端口怎么选择？

先把arduino 连上电脑


打开电脑的设备管理器

这个显示的就是端口号

回到arduino IDE ，选好芯片还有端口号 点击 烧录

常见错误：

端口号不正确：

遇到这种错误，那就先把蓝牙模块给拔掉，烧录的时候不占用tx和rx引脚

最终会成功如图示：


此时 测试舵机的代码 已经成功烧录到 单片机里面

舵机引出来一般有三根线


黑色的 那一根是 GND

中间那一 根 是 VCC

最左边那一个根是信号线

根据PCB板 丝印 提示 插上去即可

插入 电源 磁控开关 还有舵机线

然后 磁铁靠近 鱼顶 ，此时 舵机会不断地 响动

说明舵机正常

# 蓝牙测试

在板子 背面插上蓝牙 同时 ，给 arduino IDE 烧录 这一份代码：


同理，记得选择好端口 和 板子类型 （建议把 arduino Nano 拔下来烧录）

接着，手机安装 蓝牙调试器（安装包已随仓库提供： 软件/蓝牙调试器_v1.95.apk ，该软件来自第三方 网络，版权归原作者所有）

进入蓝牙调试器，连接对应的蓝牙

在发送区发送对应的指令 比如 CMD_a / CMD_b / CMD_A 等

更多指令详见于 指令说明文档

如果鱼正常运行，说明电控模块正常。
配重

鱼的内嵌模块正常之后，就是调配重环节

给电路模块打上热熔胶

然后包裹上一层塑料密封袋，再配上一些包一些面巾纸做防水

在水盆里面调整一下配重

# 密封检查

配重完成之后，密封鱼的旋钮处

然后装上磁铁

注意，磁铁一定一定要注意方向！！！

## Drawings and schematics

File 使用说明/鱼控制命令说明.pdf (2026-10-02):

## 1. 基础模式（默认模式）

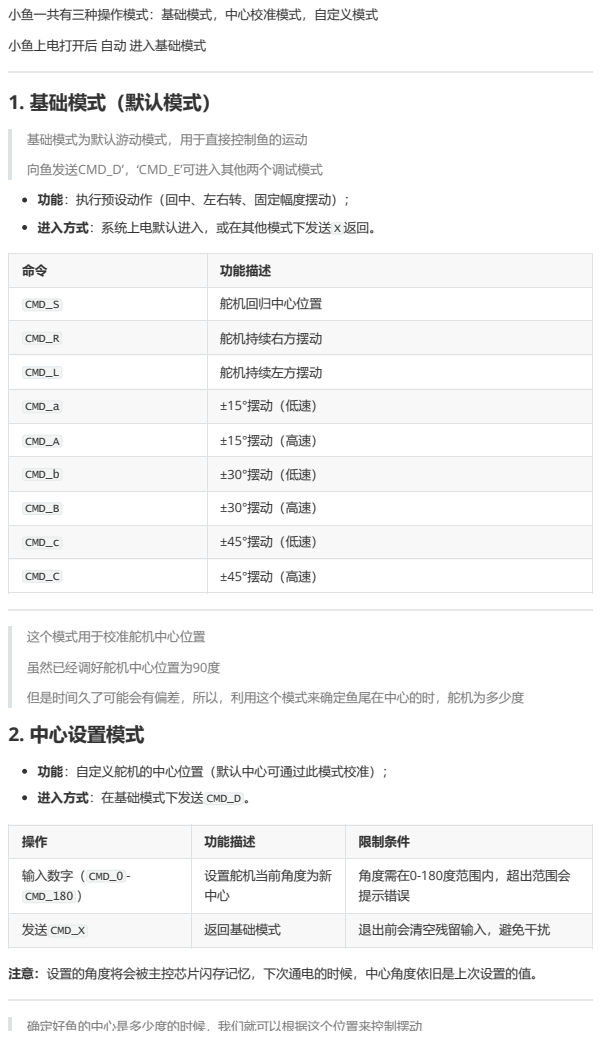
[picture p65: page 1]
确定好鱼的中心是多少度的时候，我们就可以根据这个位置来控制摆动

小鱼一共有三种操作模式：基础模式，中心校准模式，自定义模式
小鱼上电打开后 自动 进入基础模式

基础模式为默认游动模式，用于直接控制鱼的运动
向鱼发送CMD_D’，‘CMD_E’可进入其他两个调试模式
功能：执行预设动作（回中、左右转、固定幅度摆动）；
进入方式：系统上电默认进入，或在其他模式下发送 X 返回。

命令 | 功能描述

CMD_S | 舵机回归中心位置

CMD_R | 舵机持续右方摆动

CMD_L | 舵机持续左方摆动

CMD_a | ±15°摆动（低速）

CMD_A | ±15°摆动（高速）

CMD_b | ±30°摆动（低速）

CMD_B | ±30°摆动（高速）

CMD_c | ±45°摆动（低速）

CMD_C | ±45°摆动（高速）

这个模式用于校准舵机中心位置
虽然已经调好舵机中心位置为90度
但是时间久了可能会有偏差，所以，利用这个模式来确定鱼尾在中心的时，舵机为多少度
2. 中心设置模式

功能：自定义舵机的中心位置（默认中心可通过此模式校准）；
进入方式：在基础模式下发送 CMD_D 。

操作 | 功能描述 | 限制条件

输入数字（ CMD_0 -CMD_180 ） | 设置舵机当前角度为新 中心 | 角度需在0-180度范围内，超出范围会 提示错误

发送 CMD_X | 返回基础模式 | 退出前会清空残留输入，避免干扰

注意：设置的角度将会被主控芯片闪存记忆，下次通电的时候，中心角度依旧是上次设置的值。

## 3. 自定义模式

### 输入格式1

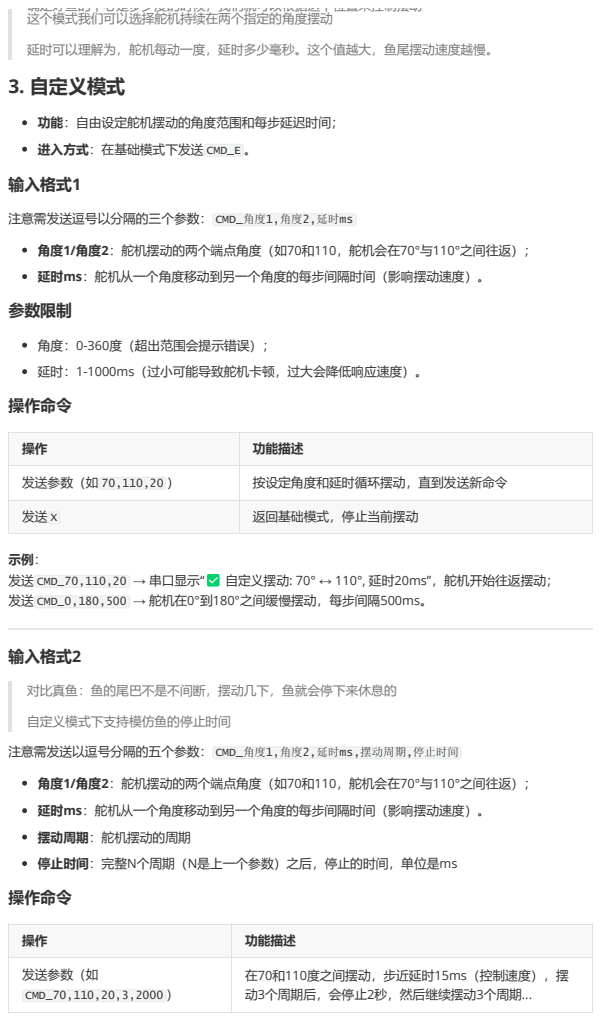
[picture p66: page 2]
功能：自由设定舵机摆动的角度范围和每步延迟时间；; 进入方式：在基础模式下发送 CMD_E 。; 输入格式2

确定好鱼的中心是多少度的时候，我们就可以根据这个位置来控制摆动
这个模式我们可以选择舵机持续在两个指定的角度摆动
延时可以理解为，舵机每动一度，延时多少毫秒。这个值越大，鱼尾摆动速度越慢。

注意需发送逗号以分隔的三个参数： CMD_角度1,角度2,延时ms
角度1/角度2：舵机摆动的两个端点角度（如70和110，舵机会在70°与110°之间往返）；
延时ms：舵机从一个角度移动到另一个角度的每步间隔时间（影响摆动速度）。
参数限制

角度：0-360度（超出范围会提示错误）；
延时：1-1000ms（过小可能导致舵机卡顿，过大会降低响应速度）。
操作命令

操作 | 功能描述

发送参数（如 70,110,20 ） | 按设定角度和延时循环摆动，直到发送新命令

发送 X | 返回基础模式，停止当前摆动

发送 CMD_70,110,20 → 串口显示“✅ 自定义摆动: 70° ↔ 110°, 延时20ms”，舵机开始往返摆动；
发送 CMD_0,180,500 → 舵机在0°到180°之间缓慢摆动，每步间隔500ms。

对比真鱼：鱼的尾巴不是不间断，摆动几下，鱼就会停下来休息的
自定义模式下支持模仿鱼的停止时间

注意需发送以逗号分隔的五个参数： CMD_角度1,角度2,延时ms,摆动周期,停止时间
摆动周期：舵机摆动的周期
停止时间：完整N个周期（N是上一个参数）之后，停止的时间，单位是ms

发送参数（如 CMD_70,110,20,3,2000 ） | 在70和110度之间摆动，步近延时15ms（控制速度），摆 动3个周期后，会停止2秒，然后继续摆动3个周期...

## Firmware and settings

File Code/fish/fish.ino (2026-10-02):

/*
 * 舵机控制程序 - 主程序
 * 功能：通过串口命令控制舵机执行各种动作
 * 使用Arduino Nano和Servo库
 */

#include <Servo.h>
#include "ServoControl.h"
#include "EEPROMHelper.h"
#include "ModeManager.h"

// 常量定义
#define SITE 9 //定义舵机引脚

// 全局变量定义
OperationMode currentMode = MODE_BASIC;
String serialCommand; //指令缓存区
int CENTER = 90;  //默认中心角度，会根据Flash值修改

/**
 * 初始化函数
 */
void setup() 
{  
  Serial.begin(9600);
  Serial.setTimeout(30); // 100毫秒超时，原来默认是1000ms
  loadCenterFromEEPROM();
  servoInit(SITE);
  servoMoveToCenter();
  
  Serial.println(F("舵机已初始化为中心位置"));
  Serial.println(F("=== 舵机多模式控制系统 ==="));
  Serial.println(F("默认模式: 基础模式"));
  Serial.println(F("命令格式: CMD_指令"));
  Serial.println(F("S-回中 R-右转 L-左转 A-小摆 B-中摆 C-大摆"));
  Serial.println(F("D-进入中心设置模式 E-进入自定义模式"));
  Serial.println(F("X-在任何模式下返回基础模式"));

  // 清空串口缓冲区
  while(Serial.available()) Serial.read();
}

/**
 * 主循环函数
 */
void loop() 
{
  switch(currentMode) 
  {
    case MODE_BASIC:
      Basic_Mode();
      break;
    case MODE_CENTER_SET:
      Set_Center_Mode();
      break;
    case MODE_CUSTOM:
      Custom_Mode();
      break;
  }
}

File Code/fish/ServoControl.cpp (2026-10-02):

#include "ServoControl.h"
#include <Servo.h>  // 包含Servo库

// 创建舵机对象
Servo servo1;

// 舵机初始化函数
void servoInit(int pin) 
{
  servo1.attach(pin);  // 关联舵机到指定引脚
}

/**
 * 缓慢移动舵机到中心位置
 * 功能：逐步移动舵机，每步延迟10ms，直到到达中心位置
 * 注意：移动过程中会检查串口输入，如有数据则中断移动
 */
void servoMoveToCenter() 
{
  int angle = servo1.read(); // 读取当前角度
  int way = angle > CENTER  ? 0 : 1; // 确定移动方向：0=减小角度，1=增加角度
  
  // 逐步移动至中心位置
  while (angle != CENTER ) 
  {
    angle = servo1.read();
    servo1.write(way ? angle + 1 : angle - 1); // 逐步移动
    delay(10); // 控制移动速度
  }
}


/**
 * 平滑移动函数
 * @param fromAngle 起始角度
 * @param toAngle 目标角度
 * @param stepDelay 每步延迟(ms)，控制速度
 */
void smoothMove(int fromAngle, int toAngle, int stepDelay) 
{
    servo1.write(fromAngle); // 先快速定位到起始角度
    delay(50); // 短暂延迟确保舵机就位
    smoothMoveTo(toAngle, stepDelay); // 然后平滑移动到目标角度
}

/**
 * 平滑移动函数（从当前位置移动到目标角度）
 * 这是主要的移动函数，推荐使用
 */
void smoothMoveTo(int toAngle, int stepDelay) 
{
    int currentAngle = servo1.read();
    int steps = abs(toAngle - currentAngle);
    int direction = (toAngle > currentAngle) ? 1 : -1;
    
    for(int i = 1; i <= steps; i++) 
    {
        int newAngle = currentAngle + (i * direction);
        servo1.write(newAngle);
        delay(stepDelay);
    }
}

void smoothServo_Swing15_L() 
{
  int startAngle = servo1.read();  // 获取当前位置
  int targetAngle1 = CENTER - 15; // 目标位置1：85度
  int targetAngle2 = CENTER + 15; // 目标位置2：115度
  
  // 第一步：平滑移动到85度
  smoothMove(startAngle, targetAngle1, 15); // 15ms步进间隔
  
  // 短暂停留
  delay(200);
  
  // 第二步：平滑移动到115度
  smoothMove(targetAngle1, targetAngle2, 15);
  
  // 短暂停留
  delay(200);
}


/**
 * 平滑30度摆动函数
 * 功能：实现舵机从当前位置平滑摆动到中心±30度的位置
 * 摆动范围：从中心-30度到中心+30度（例如中心为100度时：70度↔130度）
 * 特点：使用分段步进平滑移动，运动轨迹自然流畅
 */
void smoothServo_Swing30_L() 
{
  // 获取舵机当前角度位置
  int startAngle = servo1.read();
  
  // 计算摆动目标角度
  int targetAngle1 = CENTER - 30; // 左摆动目标位置（中心-30度）
  int targetAngle2 = CENTER + 30; // 右摆动目标位置（中心+30度）
  
  // 第一步：平滑移动到左端位置
  smoothMove(startAngle, targetAngle1, 10); // 10ms步进间隔，控制移动速度
  
  // 在左端位置短暂停留200ms
  delay(200);
  
  // 第二步：平滑移动到右端位置
  smoothMove(targetAngle1, targetAngle2, 10); // 相同的步进间隔保持运动一致性
  
  // 在右端位置短暂停留200ms
  delay(200);
  
}

/**
 * 平滑45度摆动函数
 * 功能：实现舵机从当前位置平滑摆动到中心±45度的位置
 * 摆动范围：从中心-45度到中心+45度（例如中心为100度时：55度↔145度）
 * 特点：更大范围的平滑摆动，适合需要广泛扫描的应用场景
 */
void smoothServo_Swing45_L() 
{
  // 获取舵机当前角度位置
  int startAngle = servo1.read();
  
  // 计算摆动目标角度
  int targetAngle1 = CENTER - 45; // 左摆动目标位置（中心-45度）
  int targetAngle2 = CENTER + 45; // 右摆动目标位置（中心+45度）
  
  // 第一步：平滑移动到左端位置
  smoothMove(startAngle, targetAngle1, 8); // 稍长的步进间隔（25ms），因移动距离更大
  
  // 在左端位置短暂停留250ms（稍长停留时间）
  delay(250);
  
  // 第二步：平滑移动到右端位置
  smoothMove(targetAngle1, targetAngle2, 8); // 保持一致的移动速度
  
  // 在右端位置短暂停留250ms
  delay(250);
}

void smoothServo_Swing15_H() 
{
  int startAngle = servo1.read();  // 获取当前位置
  int targetAngle1 = CENTER - 15; // 目标位置1：85度
  int targetAngle2 = CENTER + 15; // 目标位置2：115度
  
  // 第一步：平滑移动到85度
  smoothMove(startAngle, targetAngle1, 1); // 20ms步进间隔
  
  // 短暂停留
  delay(200);
  
  // 第二步：平滑移动到115度
  smoothMove(targetAngle1, targetAngle2, 1);
  
  // 短暂停留
  delay(200);
}


/**
 * 平滑30度摆动函数
 * 功能：实现舵机从当前位置平滑摆动到中心±30度的位置
 * 摆动范围：从中心-30度到中心+30度（例如中心为100度时：70度↔130度）
 * 特点：使用分段步进平滑移动，运动轨迹自然流畅
 */
void smoothServo_Swing30_H() 
{
  // 获取舵机当前角度位置
  int startAngle = servo1.read();
  
  // 计算摆动目标角度
  int targetAngle1 = CENTER - 30; // 左摆动目标位置（中心-30度）
  int targetAngle2 = CENTER + 30; // 右摆动目标位置（中心+30度）
  
  // 第一步：平滑移动到左端位置
  smoothMove(startAngle, targetAngle1, 1); // 20ms步进间隔，控制移动速度
  
  // 在左端位置短暂停留200ms
  delay(200);
  
  // 第二步：平滑移动到右端位置
  smoothMove(targetAngle1, targetAngle2, 1); // 相同的步进间隔保持运动一致性
  
  // 在右端位置短暂停留200ms
  delay(200);
  
}

/**
 * 平滑45度摆动函数
 * 功能：实现舵机从当前位置平滑摆动到中心±45度的位置
 * 摆动范围：从中心-45度到中心+45度（例如中心为100度时：55度↔145度）
 * 特点：更大范围的平滑摆动，适合需要广泛扫描的应用场景
 */
void smoothServo_Swing45_H() 
{
  // 获取舵机当前角度位置
  int startAngle = servo1.read();
  
  // 计算摆动目标角度
  int targetAngle1 = CENTER - 45; // 左摆动目标位置（中心-45度）
  int targetAngle2 = CENTER + 45; // 右摆动目标位置（中心+45度）
  
  // 第一步：平滑移动到左端位置
  smoothMove(startAngle, targetAngle1, 1); // 稍长的步进间隔（25ms），因移动距离更大
  
  // 在左端位置短暂停留250ms（稍长停留时间）
  delay(250);
  
  // 第二步：平滑移动到右端位置
  smoothMove(targetAngle1, targetAngle2, 1); // 保持一致的移动速度
  
  // 在右端位置短暂停留250ms
  delay(250);
}

/**
 * 右转动作循环
 * 功能：舵机先向右转动到170度，保持500ms，然后返回中心位置100度，保持280ms
 * 动作流程：100 → 170 → 100 → ...
 * 循环执行直到串口有新命令输入
 */
void servoRightSwing() 
{
  servo1.write(CENTER + 75);  // 计算得到170度位置（90+80=170）
  delay(320);                  // 在右端位置保持500ms
  servo1.write(CENTER + 20);   //90+15=115
  delay(320);                  // 在中心位置保持200ms
}

/**
 * 左转动作循环
 * 功能：舵机先向左转动到10度，保持500ms，然后返回中心位置100度，保持280ms
 * 动作流程：100 → 10 → 100 → ...
 * 循环执行直到串口有新命令输入
 */
void servoLeftSwing() 
{
  servo1.write(CENTER - 75);   // 计算得到10度位置（100-90=10）
  delay(350);                  // 在左端位置保持500ms
  servo1.write(CENTER - 20);        // 返回中心位置
  delay(350);                  // 在中心位置保持200ms
}

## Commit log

2026-10-02 仿生鱼教育项目：代码、PCB、外壳与说明文档
    [前盖.STEP, 右胸鳍.STEP, 后壳单轴舵机.STEP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]
2026-10-02 完善 README，添加 MIT LICENSE 与系统文件忽略规则
